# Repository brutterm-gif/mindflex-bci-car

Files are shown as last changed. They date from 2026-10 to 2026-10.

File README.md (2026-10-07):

# MindFlex BCI – EEG-controlled RC car

**English** | [Deutsch](README.de.md)

A brain-computer interface project: a modified MindFlex EEG headset sends its readings through
an Arduino – over USB or wirelessly via Bluetooth LE. A Python application analyses the signals
in real time, trains several machine-learning models on recorded sessions and turns their
predictions into driving commands for a self-designed, 3D-printed RC car with four motors.

Built as the practical part of a school research paper (*Seminarfacharbeit*) on
*“Brain-computer interfaces – how thoughts control machines”*.

<p align="center">
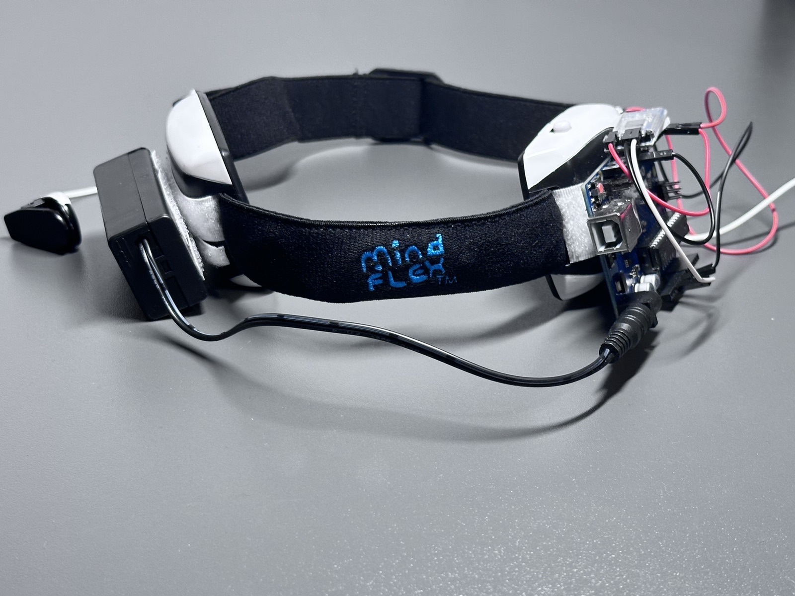
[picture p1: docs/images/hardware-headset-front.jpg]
The MindFlex headset from the front with Arduino and 9 V battery
  
</p>

<p align="center">
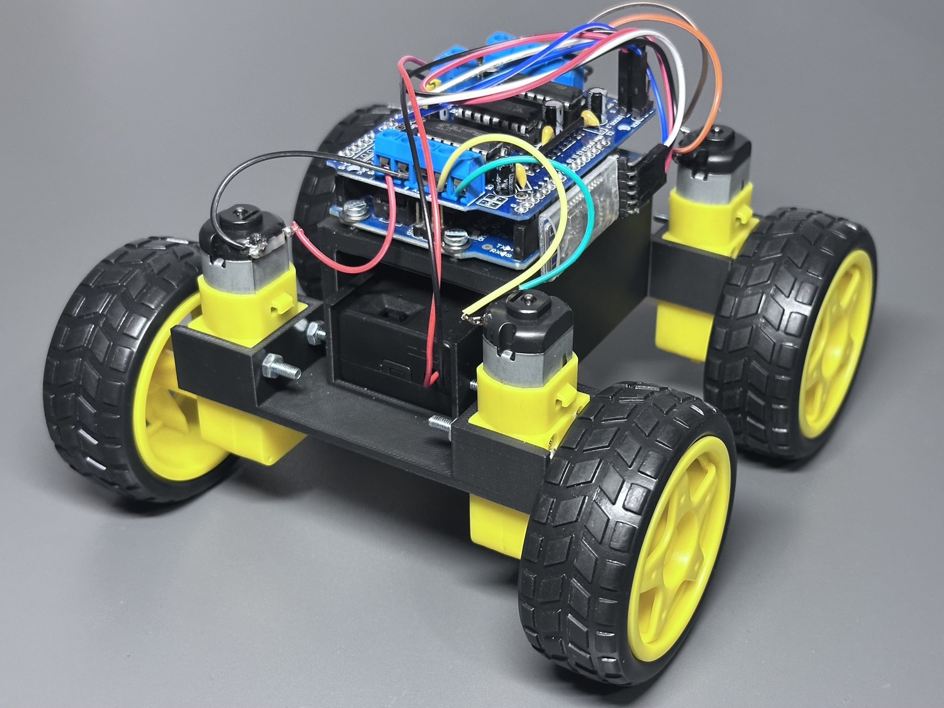
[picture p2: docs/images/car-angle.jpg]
The finished RC car with 3D-printed chassis, four motors and an Arduino with motor shield
  
</p>

**[⬇ Download version 3.4](https://github.com/brutterm-gif/mindflex-bci-car/releases/latest)** ·
[Parts list](docs/TEILELISTE.md) · [Wiring](docs/images/wiring.svg) ·
[Architecture](docs/ARCHITEKTUR.md)

> The application interface and the detailed documentation in `docs/` are in German.

## Screenshots

Live prediction with EEG history, eSense values, driving command and model accuracy:

| FORWARD | STOP |
|---|---|
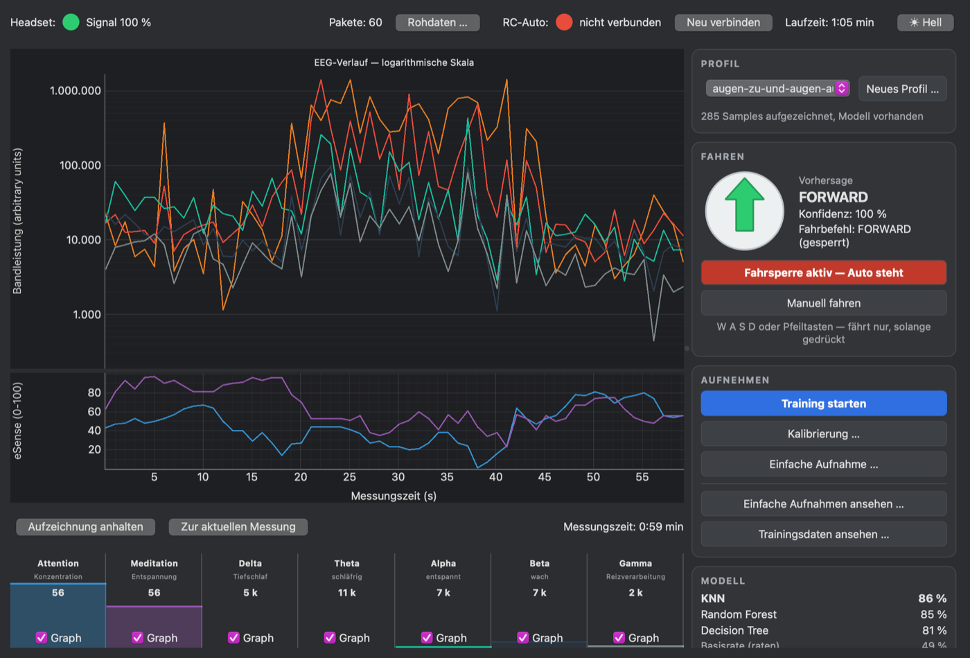
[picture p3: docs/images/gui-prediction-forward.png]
Prediction FORWARD
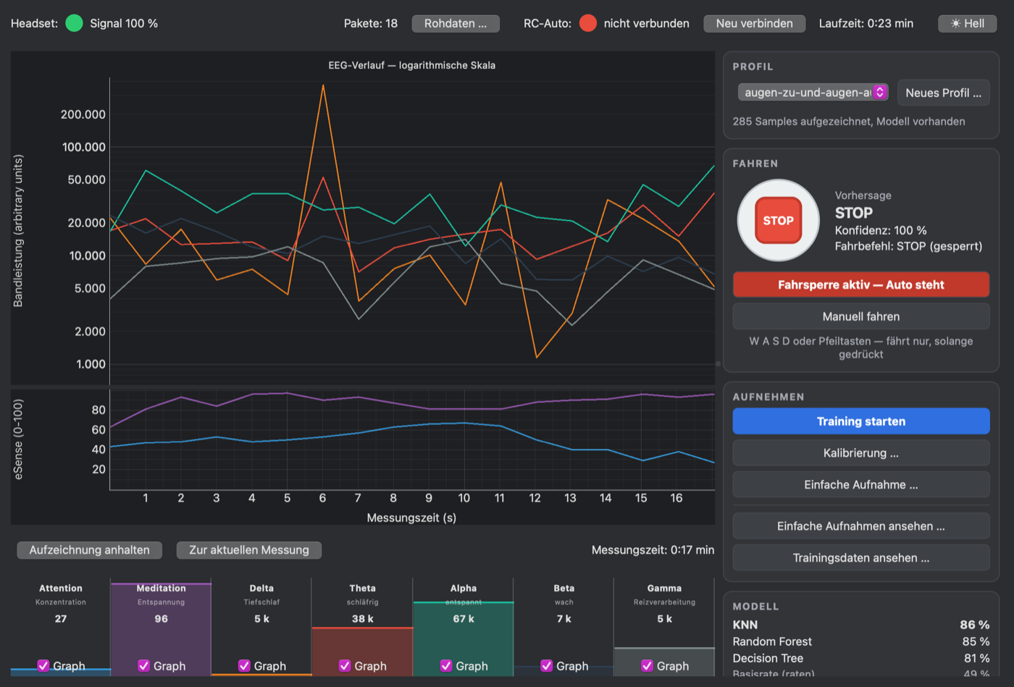
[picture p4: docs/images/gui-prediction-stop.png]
Prediction STOP
|  |  |

| Calibration | Confusion matrix |
|---|---|
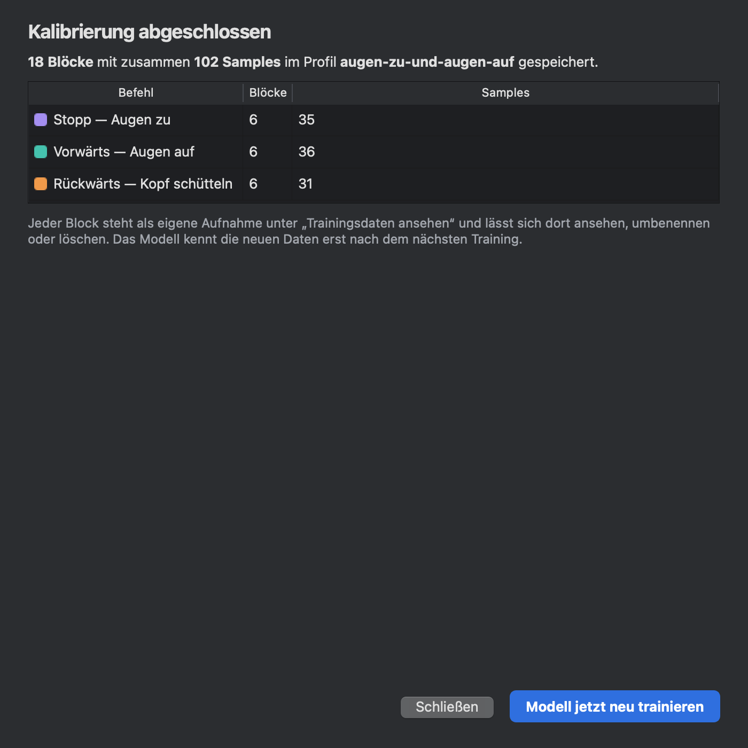
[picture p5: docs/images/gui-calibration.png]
Calibration finished
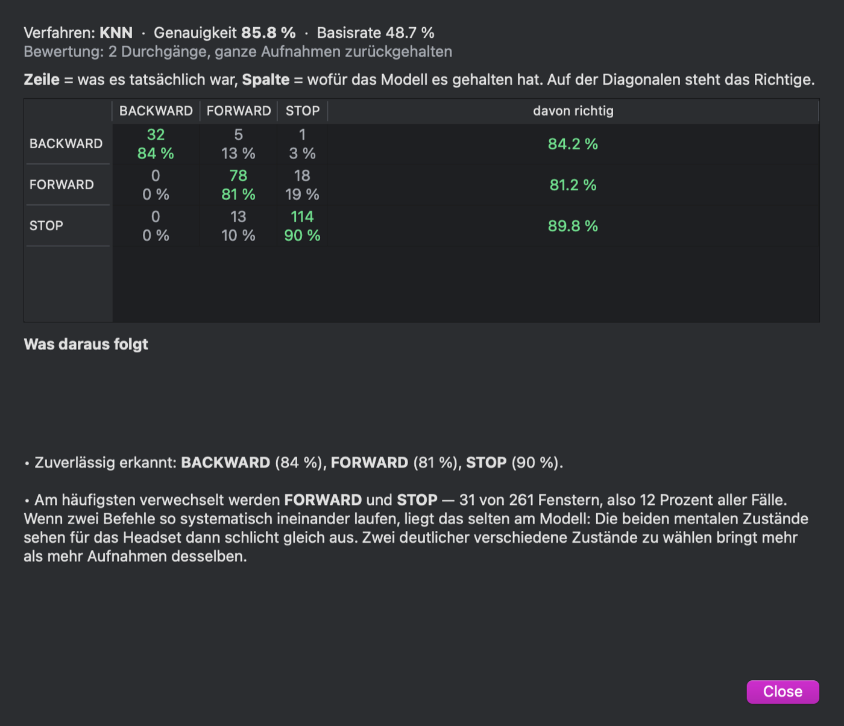
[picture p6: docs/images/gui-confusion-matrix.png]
Confusion matrix of the KNN model
|  |  |

<details>
<summary><b>More screenshots</b></summary>

| Prediction BACKWARD | Car connected, drive lock off |
|---|---|
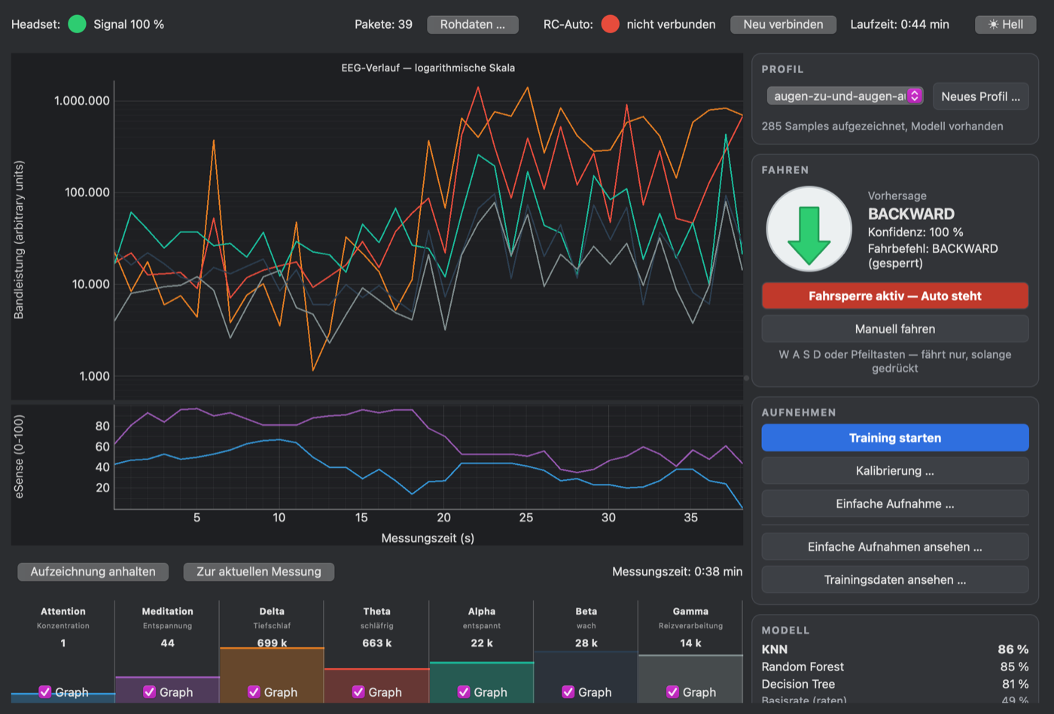
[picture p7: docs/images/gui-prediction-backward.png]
Prediction BACKWARD
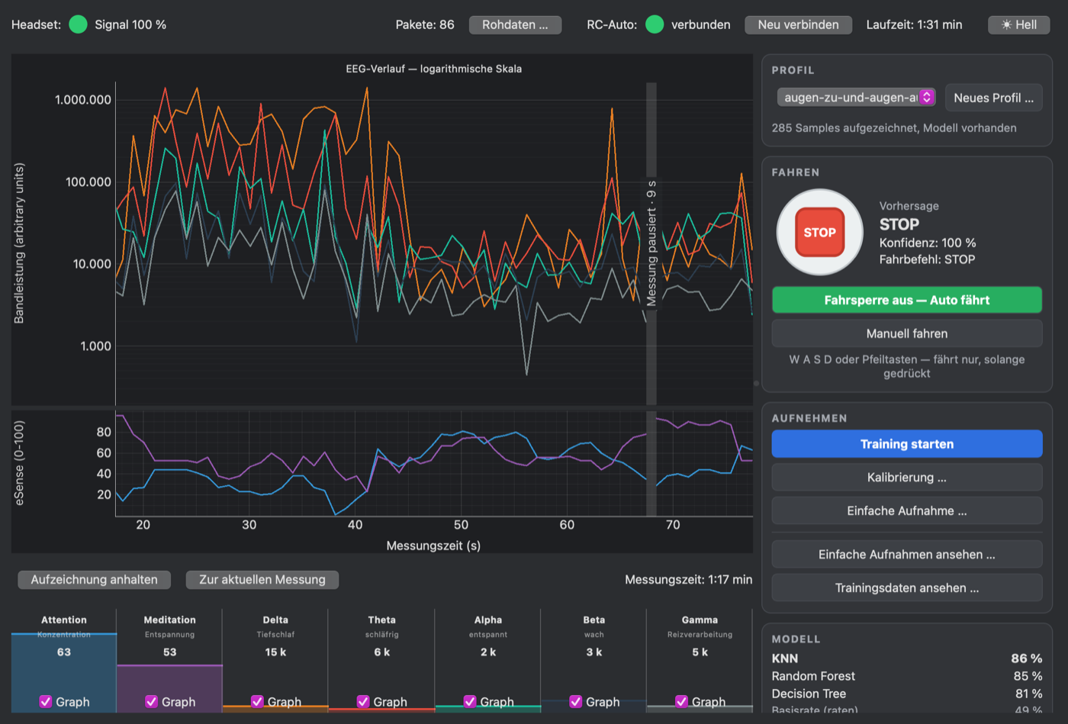
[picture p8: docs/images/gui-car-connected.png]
Car connected, drive lock off
|  |  |

| Manual driving (W A S D) | Headset without skin contact |
|---|---|
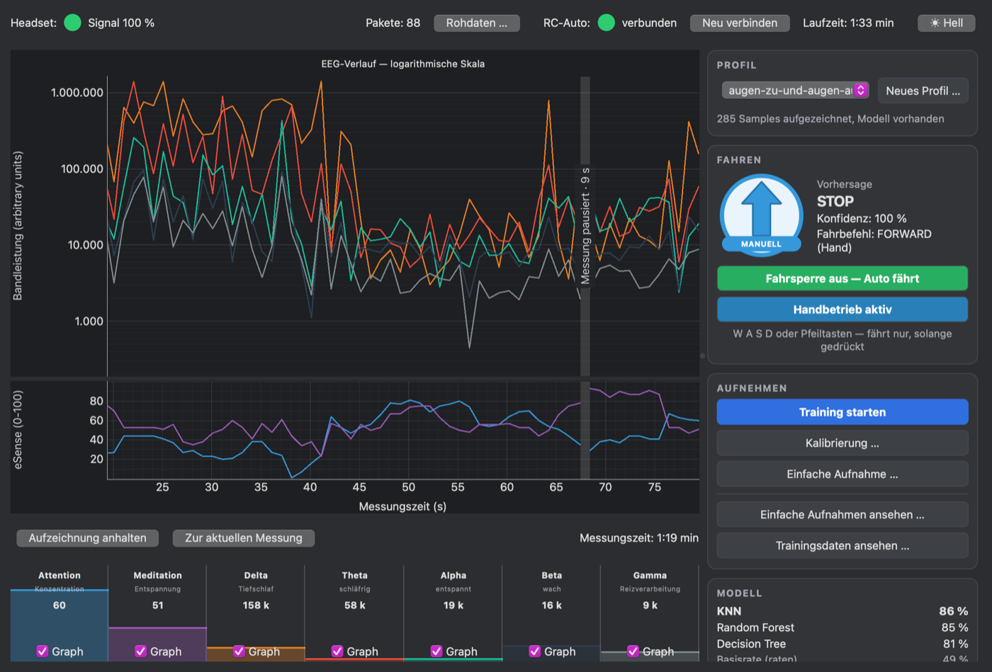
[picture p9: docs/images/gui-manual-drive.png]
Manual driving
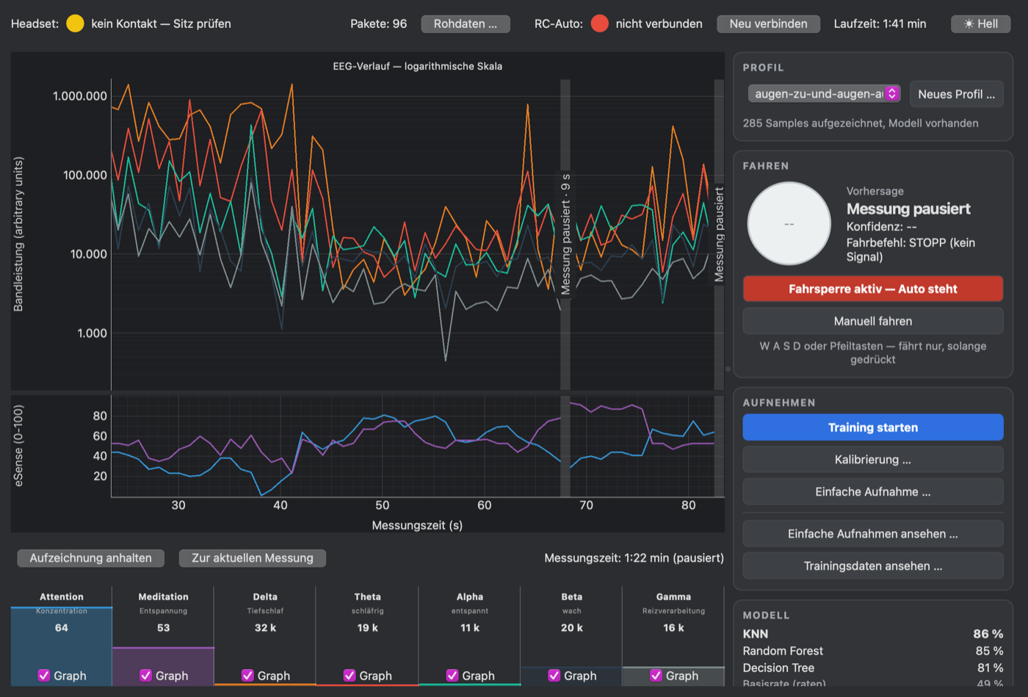
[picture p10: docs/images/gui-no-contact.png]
Headset without skin contact, recording paused
|  |  |

| Calibration running | Light mode |
|---|---|
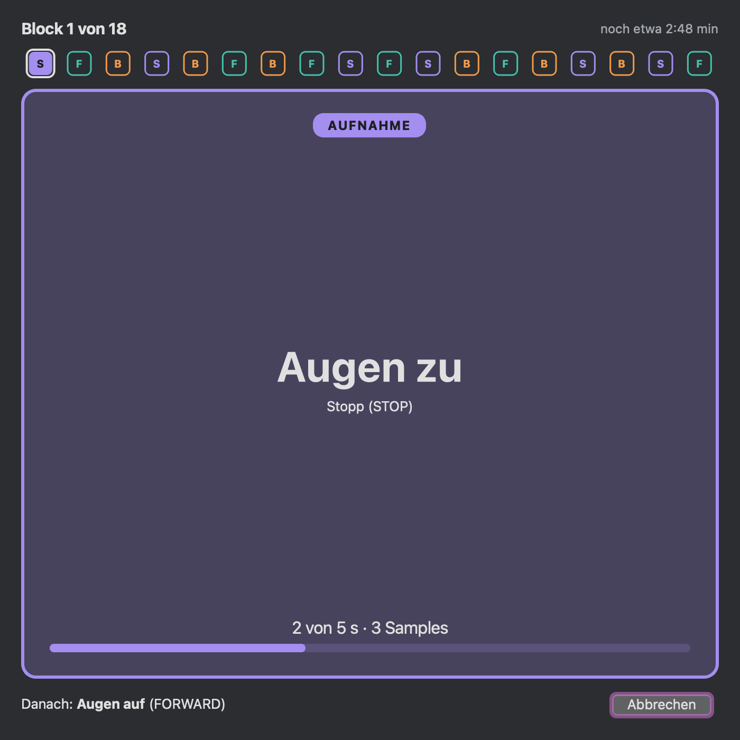
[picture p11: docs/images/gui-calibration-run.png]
Calibration: block 1 of 18, eyes closed
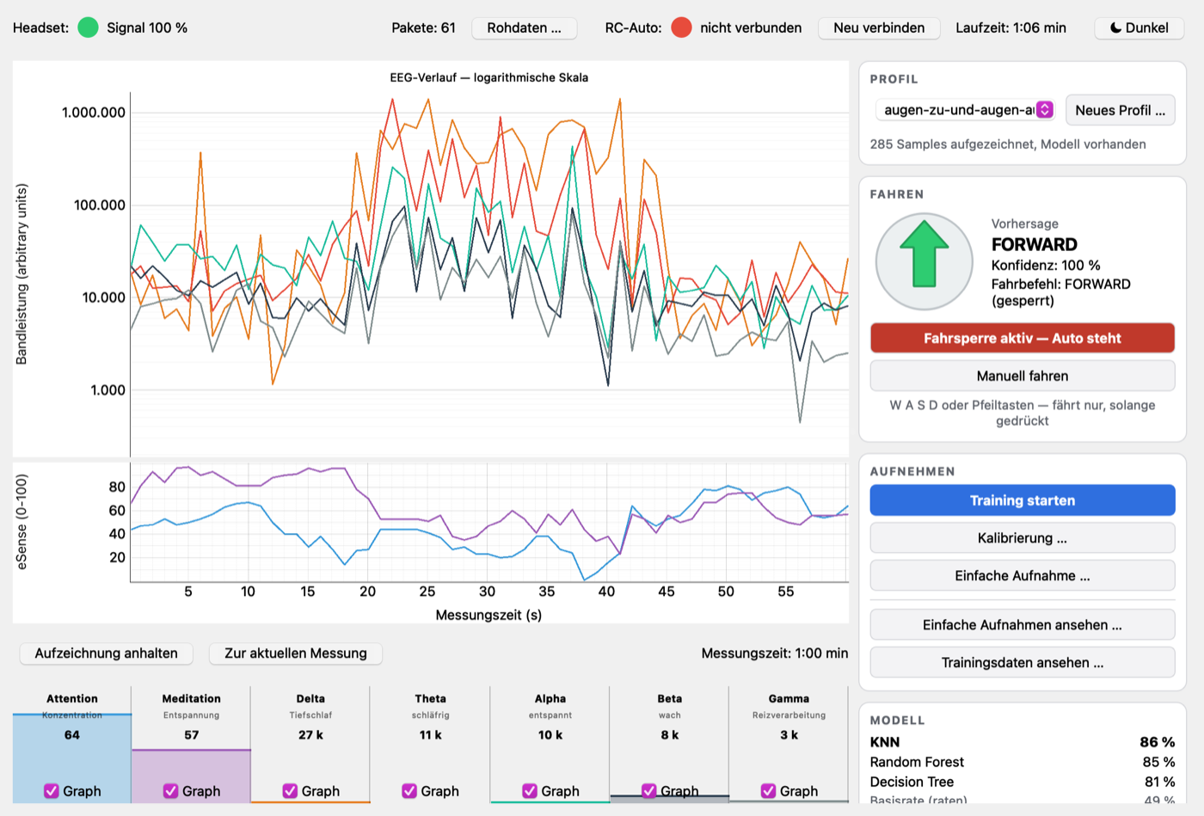
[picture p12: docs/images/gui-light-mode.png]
Light mode
|  |  |

| Training data with recommendations | Single recording as a graph |
|---|---|
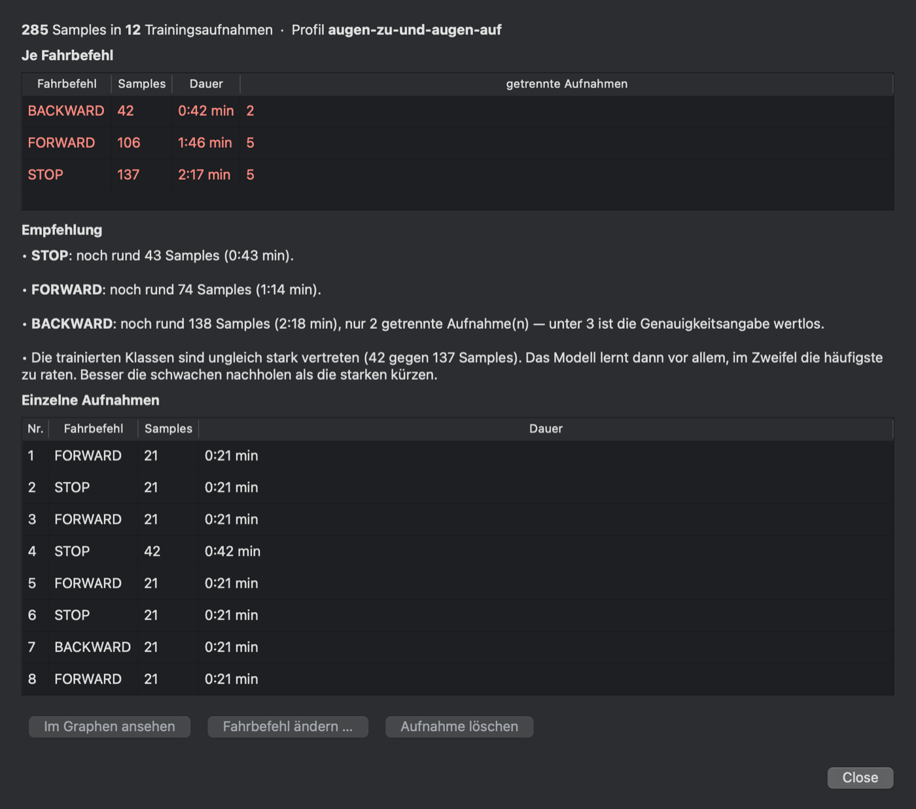
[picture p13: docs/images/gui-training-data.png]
Overview of the training data
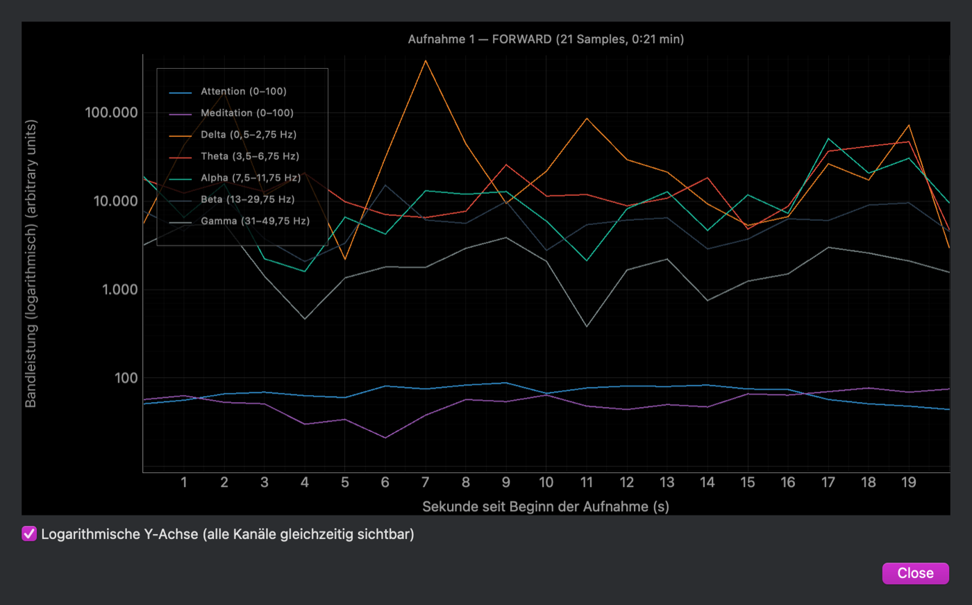
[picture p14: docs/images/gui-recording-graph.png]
Recording FORWARD as a graph
|  |  |

</details>

## Results

The headset measures with a single electrode on the forehead. That is enough to tell apart
states that show up clearly there – not “thinking left or right”. The car is therefore
controlled with three states you can produce on purpose:

| Command | What you do | Why it works |
|---|---|---|
| STOP | close your eyes | alpha waves rise sharply (Berger effect) |
| FORWARD | open your eyes | alpha drops again |
| BACKWARD | shake your head or clench your jaw | muscle signal picked up by the forehead electrode |

**Accuracy** (one profile, three commands, 12 recordings totalling 285 seconds, evaluated on
held-out whole recordings):

| Method | Accuracy |
|---|---|
| k-nearest neighbours | **85.8 %** |
| Random forest | 85 % |
| Decision tree | 81 % |
| Baseline (always guess the most frequent class) | 48.7 % |

STOP was recognised correctly 90 % of the time, BACKWARD 84 % and FORWARD 81 %. The most common
confusion is FORWARD vs. STOP – mostly right after opening the eyes, because alpha only drops
after 2–3 seconds.

These numbers are for one person and a small amount of data. BACKWARD has only two separate
recordings; the application itself warns that its figure is therefore still uncertain. Models
do not transfer between people; everyone needs their own profile.

## Project structure

```
MindFlex_BCI_Projekt/   Python application: data input (USB/BLE), feature extraction,
                        training and classification (KNN, random forest, decision tree),
                        PyQt5 GUI with calibration, profiles, drive lock and manual driving,
                        car control
  arduino/              sketches for the EEG Arduino and the RC car
BrainGrapher/           Processing sketch for live visualisation of the raw EEG values,
                        extended with a Bluetooth bridge (ble_bridge.py)
BrainGrapher_Python/    port of the BrainGrapher to Python (PyQt5/pyqtgraph)
hardware/               3D model of the chassis (STL)
docs/                   architecture, parts list, images
```

## Origin and own work

`BrainGrapher/` is based on the open-source
[Processing Brain Grapher](https://github.com/kitschpatrol/Processing-Brain-Grapher) by
Eric Mika (MIT licence, see [`BrainGrapher/LICENSE.txt`](BrainGrapher/LICENSE.txt)). It served
as the starting point for reliably receiving and visualising the headset's data. Bluetooth LE
support was added. `BrainGrapher_Python/` is a port of that sketch to Python.

The sketch `mindflex_eeg.ino` is based on the *BrainSerialTest* example of the
[Arduino Brain Library](https://github.com/kitschpatrol/Brain), also by Eric Mika.

`MindFlex_BCI_Projekt/` is original work: the data pipeline (validation, ring buffer, feature
extraction), the training and classification system with automatic selection of the best
model, the GUI with calibration and profiles, the Bluetooth link and the RC car control. The
sketch `rc_car_4wd.ino` and the chassis are original work as well.

## Hardware

All components: [parts list](docs/TEILELISTE.md). Wiring:

Wiring: headset with Arduino Uno, car with Duemilanove and L293D shield

1. **Headset and EEG Arduino (Uno):** The MindFlex contains NeuroSky's TGAM module. Two wires
   are soldered to its T pin and GND and lead to the Arduino. Using the
   [Arduino Brain Library](https://github.com/kitschpatrol/Brain), the Uno outputs one CSV line
   per second (SignalQuality, Attention, Meditation, Delta, Theta, LowAlpha, HighAlpha, LowBeta,
   HighBeta, LowGamma, HighGamma) – over USB or a BLE module. Arduino and radio sit directly on
   the headset, powered by a switched 9 V battery.

| Headset mit Arduino · Headset with Arduino | Vorderansicht · Front view |
|---|---|
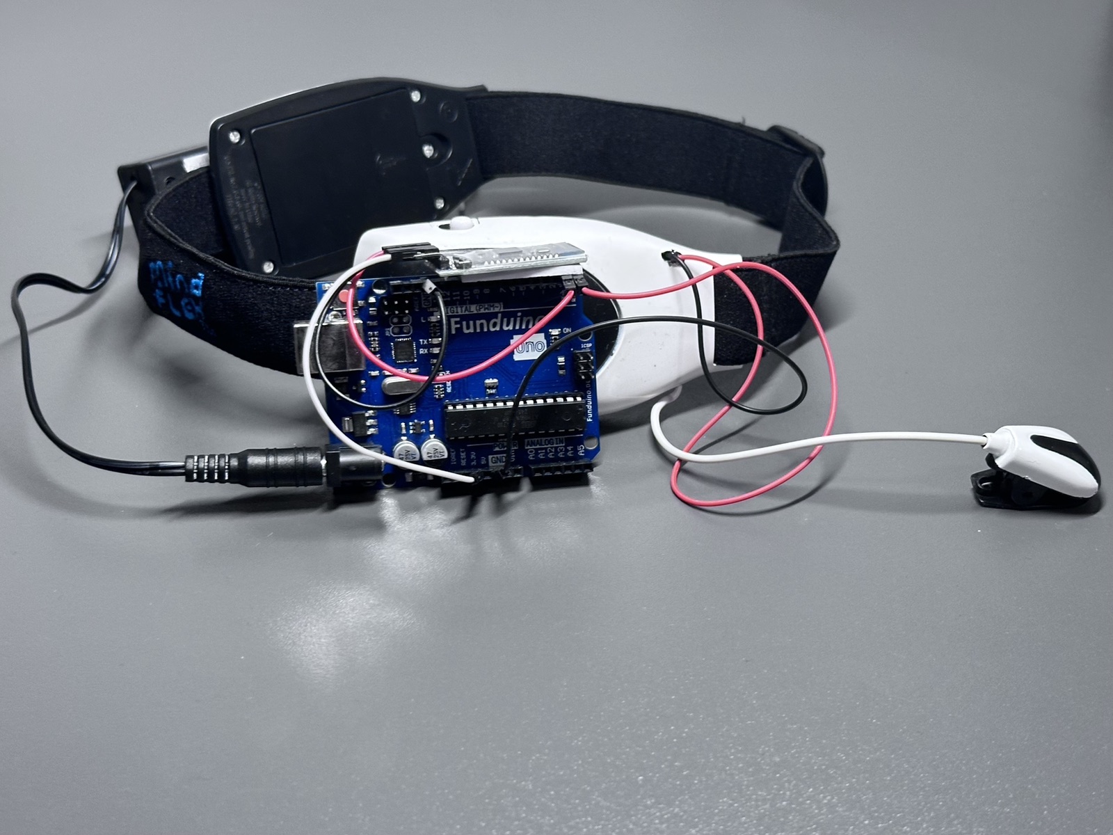
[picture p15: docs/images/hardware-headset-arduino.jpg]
MindFlex headset with Arduino Uno and BLE module attached
|  | MindFlex headset from the front |
| **Geöffnet: TGAM-Modul mit angelöteten Drähten · Opened: TGAM module with soldered wires** | **Rückseite: 9-V-Block und Ohrclip · Back: 9 V battery and ear clip** |
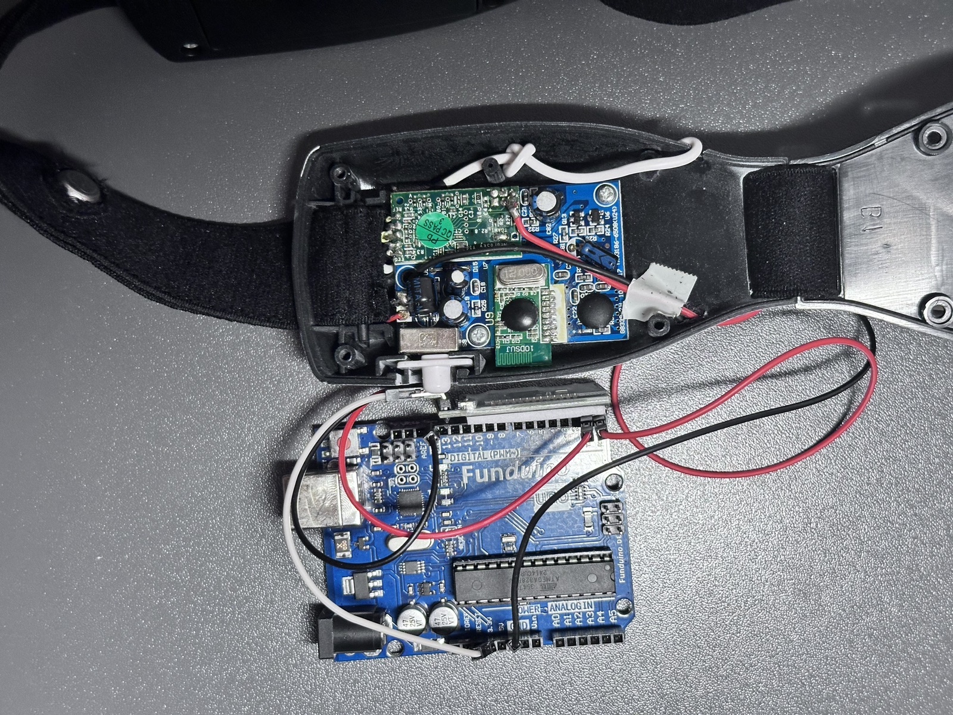
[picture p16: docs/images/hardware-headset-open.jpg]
Opened headset: green NeuroSky TGAM board with wires soldered on, leading to the Arduino
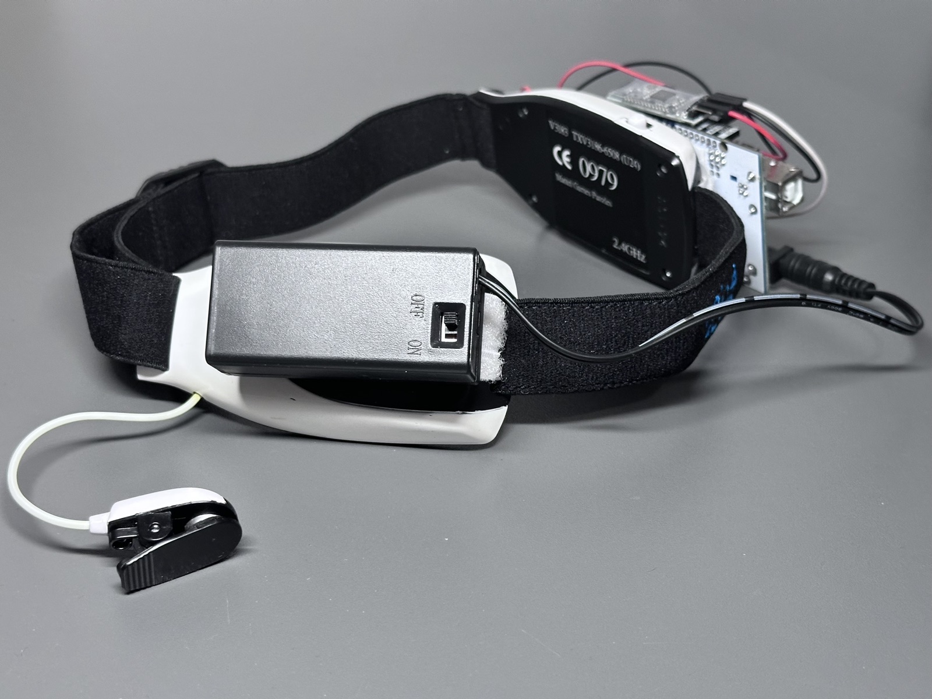
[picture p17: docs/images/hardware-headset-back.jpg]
Back of the headset with the 9 V battery box for the Arduino and the ear clip reference electrode
|  |  |

2. **RC car (Arduino Duemilanove):** receives single-character commands (`F`/`B`/`L`/`R`/`S`)
   over Bluetooth LE and drives four motors through an L293D motor shield. It steers like a
   tank: to turn, the two sides run in opposite directions. Power comes from a 9 V battery
   that sits inside the chassis below the Arduino.

| Seite mit 9-V-Block · Side with 9 V battery | Von oben · Top | Seite mit USB-Anschluss · Side with USB port |
|---|---|---|
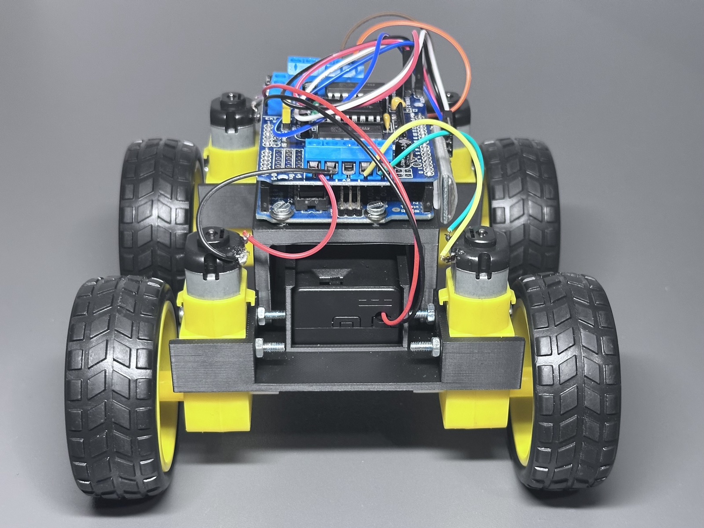
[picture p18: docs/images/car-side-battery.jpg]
RC car, side with the 9 V battery inside the chassis
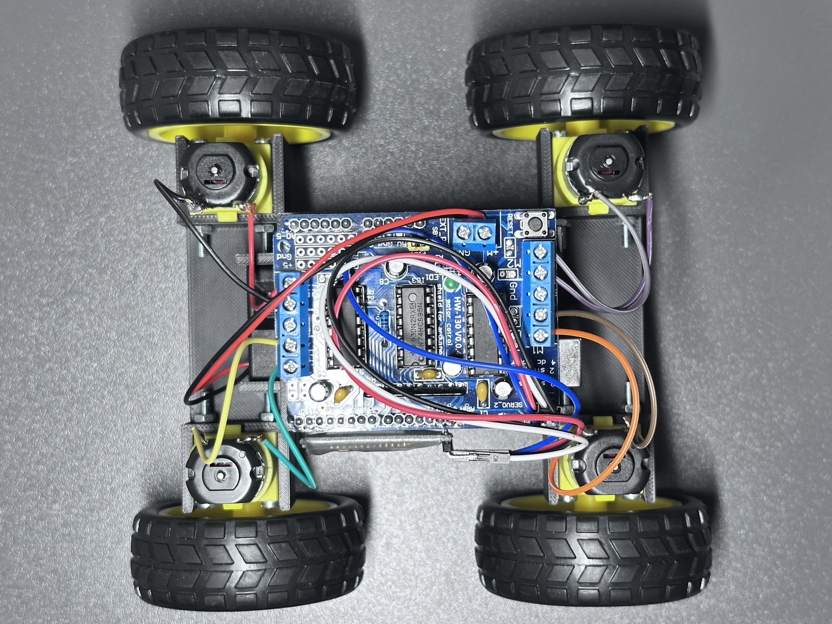
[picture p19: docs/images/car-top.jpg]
RC car from above: motor shield and wiring of the four motors
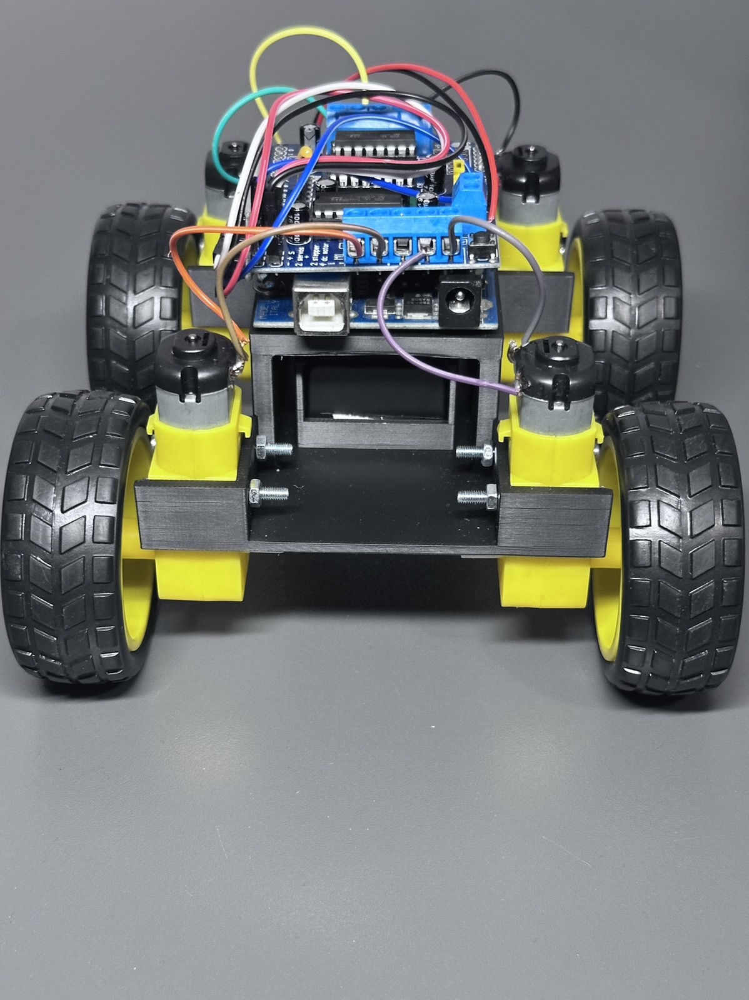
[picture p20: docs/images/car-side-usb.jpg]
RC car, side with the Arduino's USB port
|  |  |  |

| Chassis | Technische Zeichnung · Technical drawing |
|---|---|
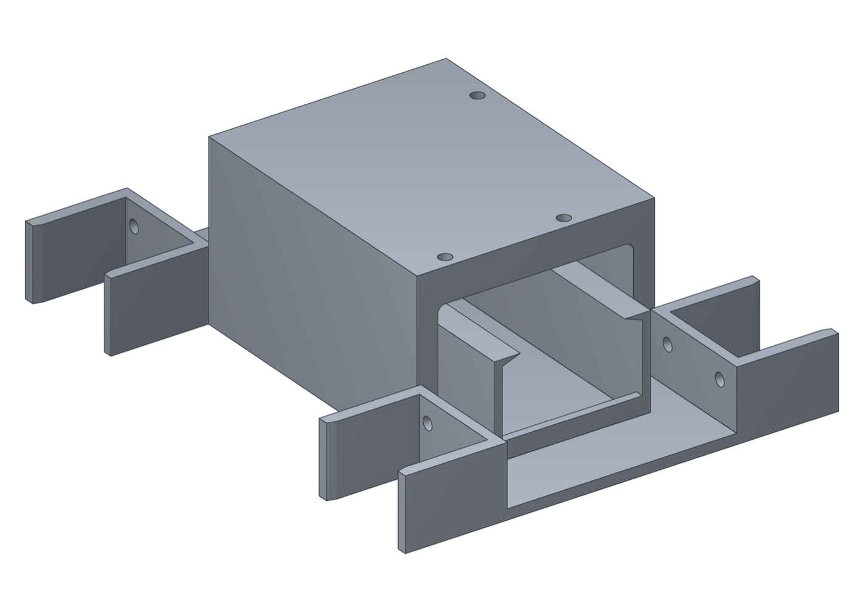
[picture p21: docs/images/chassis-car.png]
Chassis
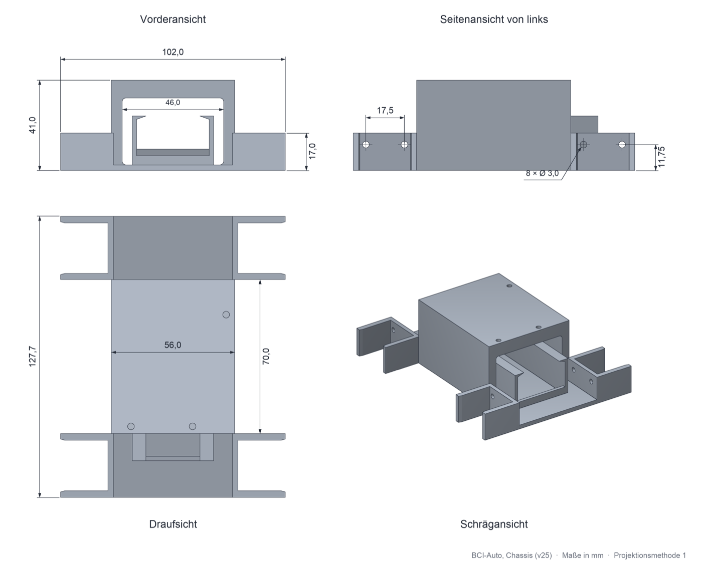
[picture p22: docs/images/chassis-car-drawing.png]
Dimensioned drawing of the chassis
|  |  |

The chassis is included as [`hardware/chassis_car.stl`](hardware/chassis_car.stl) and can be
printed directly.

## Quick start

**Requirements:** Python 3.12, the [Arduino IDE](https://www.arduino.cc/en/software) with the
[Arduino Brain Library](https://github.com/kitschpatrol/Brain) and the Adafruit Motor Shield
Library v1, optionally [Processing](https://processing.org/download) for `BrainGrapher/`.

1. Upload `MindFlex_BCI_Projekt/arduino/mindflex_eeg/mindflex_eeg.ino` to the EEG Arduino and
   `MindFlex_BCI_Projekt/arduino/rc_car_4wd/rc_car_4wd.ino` to the car's Arduino.
2. Start the Python application:

```bash
cd MindFlex_BCI_Projekt
pip install -r requirements.txt
python main.py
```

On a Mac you can also double-click `start.command`, on Windows `start.bat`. Setting up
Bluetooth, creating a profile and calibrating are described (in German) in
[`MindFlex_BCI_Projekt/README.md`](MindFlex_BCI_Projekt/README.md).

For signal visualisation only, open `BrainGrapher/BrainGrapher.pde` in the Processing IDE
(requires the ControlP5 library, available via *Sketch → Import Library → Add Library*).

## Data flow

MindFlex BCI pipeline

## Privacy

Training profiles and EEG recordings of test participants are not part of this repository.
Everyone creates and calibrates their own profile in the application; the data stays local in
the `profile/` folder.

## Licence

- `MindFlex_BCI_Projekt/`, `hardware/`, `docs/`: MIT, see [`LICENSE`](LICENSE)
- `BrainGrapher/`, `BrainGrapher_Python/`: MIT, Copyright (c) 2010-2025 Eric Mika, see
  [`BrainGrapher/LICENSE.txt`](BrainGrapher/LICENSE.txt); extensions MIT, see [`LICENSE`](LICENSE)

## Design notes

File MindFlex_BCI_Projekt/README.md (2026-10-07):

# MindFlex BCI – Anleitung

Die Python-Anwendung zum Projekt. Überblick und Hardware: [Haupt-README](../README.md),
technische Details: [`docs/ARCHITEKTUR.md`](../docs/ARCHITEKTUR.md).

## 1. Installieren

Benötigt wird **Python 3.12** ([python.org](https://www.python.org/downloads/)). Unter Windows
bei der Installation den Haken bei **„Add python.exe to PATH“** setzen.

**Mac:** Doppelklick auf `start.command`. Beim ersten Start richtet das Skript eine eigene
Python-Umgebung (`.venv`) ein und installiert die Pakete – das dauert ein paar Minuten. Meldet
macOS „nicht verifizierter Entwickler“: Rechtsklick auf `start.command` → Öffnen.

**Windows:** In diesem Ordner ein Terminal öffnen und einmalig

```
pip install -r requirements.txt
```

ausführen, danach Doppelklick auf `start.bat`.

**Von Hand (alle Systeme):**

```bash
pip install -r requirements.txt
python main.py
```

## 2. Arduinos vorbereiten

Die Sketches liegen in [`arduino/`](arduino):

| Sketch | Board | Bibliothek |
|---|---|---|
| `mindflex_eeg/` | Arduino Uno am Headset | [Arduino Brain Library](https://github.com/kitschpatrol/Brain) |
| `rc_car_4wd/` | Arduino Duemilanove im Auto | Adafruit Motor Shield Library **v1** (`AFMotor`) |
| `rc_car_test/` | Auto-Arduino, ohne Motoren | – |

Vor dem Hochladen auf den Uno das Headset ausschalten – sein Datenstrom an Pin 0 stört
sonst den Upload. Im Auto-Sketch prüft man mit `T` im Seriellen Monitor, ob alle Räder
vorwärts drehen, und stellt falsch laufende Motoren in `INVERT[]` um.

## 3. Bluetooth einrichten

Das Auto wird standardmäßig per Bluetooth angesteuert, das Headset standardmäßig per
USB-Kabel. Die Funkmodule sind BLE-Module (CC2541) und tauchen **nicht** in den
Bluetooth-Einstellungen auf.

1. Nur das Auto einschalten, dann

   ```bash
   python ble_scan.py
   ```

   Das Programm listet alle Module mit dem Dienst `FFE0` auf.
2. Adresse übernehmen – entweder dauerhaft in `config.py` (`MINDFLEX_CAR_BLE_ADDRESS`) oder
   beim Start:

   ```bash
   MINDFLEX_CAR_BLE_ADDRESS=<Adresse> python main.py
   ```

3. Zum Testen ohne EEG: `python ble_test.py` schickt jeden Befehl einmal,
   `python ble_remote.py` steuert das Auto mit W A S D (nur Mac und Linux).

Unter macOS ist die Adresse eine UUID, die auf jedem Mac anders ist – auf einem neuen Rechner
also neu suchen.

**Headset per Funk** statt Kabel (Uno mit eigenem BLE-Modul, nur das Headset eingeschaltet
lassen und ebenfalls mit `ble_scan.py` suchen):

```bash
MINDFLEX_EEG_TRANSPORT=ble MINDFLEX_EEG_BLE_ADDRESS=<Adresse> python main.py
```

## 4. Erste Schritte in der Oberfläche

1. **Profil anlegen** (oben rechts, „Neues Profil …“). Jede Person braucht ein eigenes Profil,
   denn EEG-Muster unterscheiden sich stark. Gespeichert wird in `profile/<name>/`.
2. **Headset aufsetzen** und warten, bis oben „Signal 100 %“ steht. Gelb heißt: Sitz prüfen.
3. **Kalibrierung …** starten. Das Programm führt durch 18 kurze Blöcke und sagt auf dem Mac
   jede Anweisung an (Voreinstellung: Augen zu = STOP, Augen auf = FORWARD, Kopf schütteln =
   BACKWARD; die Anweisungen lassen sich ändern). Danach „Modell jetzt neu trainieren“.
4. **Genauigkeit prüfen:** Unten rechts stehen die drei Verfahren und die Basisrate. Liegt das
   beste Verfahren nicht klar über der Basisrate, mehr Daten aufnehmen. Über
   „Trainingsdaten ansehen …“ gibt es Empfehlungen, welche Befehle noch Daten brauchen.
5. **Fahren:** Fahrsperre lösen. Mit „Manuell fahren“ lässt sich das Auto jederzeit per
   Tastatur übernehmen – es fährt nur, solange eine Taste gedrückt ist.

## 5. Weitere Startoptionen

```bash
python main.py --mode train     # Training in der Konsole statt in der Oberfläche
python main.py --mode retrain   # Modell des Profils einmal neu trainieren und beenden
```

| Umgebungsvariable | Wirkung |
|---|---|
| `MINDFLEX_PROFIL=<name>` | mit diesem Profil starten |
| `MINDFLEX_EEG_PORT=<port>` | Port des Uno fest vorgeben (z. B. `COM5` oder `/dev/cu.usbmodem…`) |
| `MINDFLEX_CAR_TRANSPORT=serial` | Auto per USB-Kabel statt Bluetooth, Port mit `MINDFLEX_CAR_PORT` |
| `MINDFLEX_ACTIVE_LABELS=STOP,FORWARD` | nur diese Befehle trainieren und vorhersagen |

Unter Windows werden Umgebungsvariablen vorher mit `set NAME=Wert` gesetzt. Das Programm
schreibt ein Protokoll nach `mindflex_bci.log`.

## 6. Dateien

| Datei | Inhalt |
|---|---|
| `main.py` und die übrigen `.py`-Dateien | das Programm |
| `config.py` | alle Einstellungen an einer Stelle |
| `profile/` | entsteht beim ersten Start; je Person Trainingsdaten, Modell und Kalibrierung. **Wird nicht zu GitHub hochgeladen.** |
| `arduino/` | die drei Sketches |
| `requirements.txt` | benötigte Python-Pakete |

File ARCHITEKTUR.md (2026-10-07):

# BCI MindFlex Car - Gesamte Vorgehensweise

Vollständige Dokumentation des BCI-Projekts: Von der Hardware-Integration über Datenerfassung bis zur KI-gesteuerten Fahrzeugkontrolle. Ein Python-basiertes System, das EEG-Signale eines MindFlex-Headsets in Echtzeit klassifiziert und daraus Fahrbefehle für ein RC-Auto ableitet.

---

## 1. Projektübersicht & Ziele

### Was ist das Projekt?

Das BCI MindFlex Car Projekt ist ein **Gedankensteuersystem für ein Fahrzeug**:
- Du trägst ein **EEG-Headset** (NeuroSky MindFlex)
- Du denkst an eine Fahrtrichtung (FORWARD, STOP, LEFT, RIGHT, BACKWARD)
- Ein **Machine-Learning-Modell** übersetzt deine Gehirnwellen in Fahrbefehle
- Ein **RC-Auto mit vier Motoren** führt diese Befehle aus

### Systemarchitektur (Datenfluss)

```
MindFlex Headset (EEG-Messungen)
        |
        v
Arduino Uno (ThinkGear-Protokoll, serieller Port)
        |
        v
Python-Anwendung (Klassifikation, GUI)
        |
        +----> Signalvalidierung & Feature-Extraktion
        |
        +----> ML-Klassifikation (Decision Tree / Random Forest / KNN)
        |
        v
BLE-Funkmodul
        |
        v
Arduino Duemilanove (Motorsteuerung)
        |
        v
L293D Shield + 4 Getriebemotoren (RC-Auto)
```

### Warum diese Architektur?

- **Zwei separate Arduinos:** Der Uno liest EEG-Daten, der Duemilanove steuert die Motoren. Das erlaubt unabhängige Fehlerbehandlung — fällt das Auto aus, läuft die Klassifikation trotzdem weiter.
- **BLE statt Klassisches Bluetooth:** Stabil auf macOS 15+, während klassisches SPP (Serial Port Profile) dort anfällig für Verbindungsabbrüche ist.
- **Python statt Arduino-Code für die KI:** Auf dem Mac kann man die ML-Modelle trainieren und debuggen, bevor man sie einsetzt.

---

## 2. Hardware-Setup

### Komponenten

**EEG-Erfassung:**
- NeuroSky MindFlex Headset (misst mit einer Elektrode auf Fp1, Referenz am Ohr)
- Arduino Uno (liest ThinkGear-Protokoll über RX-Pin)
- USB-Kabel oder BLE-Modul (CC2541 / HM-10) für drahtlose Verbindung

**Fahrzeugsteuerung:**
- Arduino Duemilanove (ATMEGA328P-PU)
- L293D Motor Shield (HW-130) für 4 DC-Motoren
- 4 Getriebemotoren (90°-Zahnräder, beliebige Drehzahl)
- 4 AA-Batterien oder LiPo (nicht 9V Block — zu schwach!)
- Bluetooth Low Energy Modul (CC2541/HM-10/AT-09) am Duemilanove

### Verkabelung: EEG-Arduino (Uno)

```
MindFlex Headset  -> RX-Pin (Pin 0)
ThinkGear Chip (aus Headset) -> RX-Pin
      |
CSV-Datenzeile (fertig aufbereitet) -> TX-Pin (Pin 1)
```

**Optional: BLE-Modul statt USB**

Wenn du das Headset funken lassen willst (2. BLE-Modul):

```
Modul VCC    -> 5V
Modul GND    -> GND
Modul RXD    -> Pin 1 (TX) über Spannungsteiler 1 kΩ / 2 kΩ   ⚠️ Zwingend!
```

Der Spannungsteiler ist **notwendig**, weil Pin 1 den Datenstrom direkt empfängt.

### Verkabelung: Auto-Arduino (Duemilanove)

```
HC-05 / HM-10 Modul
    VCC -> 5V oder 3,3V (beide getestet, Verbindung steht)
    GND -> GND
    TXD -> Pin 10 (über SoftwareSerial)
    RXD -> offen (Arduino sendet nichts zurück)

L293D Shield
    M1 -> vorne rechts
    M2 -> vorne links
    M3 -> hinten rechts
    M4 -> hinten links

Alle vier INVERT-Schalter im Sketch auf true (Motoren sind einheitlich gepolt)
```

**Versorgung:** Der Duemilanove hat auch einen 3,3-V-Pin (vom FTDI-Chip FT232RL, max. ca. 50 mA). Das BLE-Modul (ca. 10 mA) läuft daran ebenfalls, getestet am 2026-09-29.

**Wichtig:** Pin 11 darf NICHT verwendet werden (PWM für Motor 1), deshalb Pin 10 für BLE.

---

## 3. Komponenten-Auswahl & Begründung

Dieses Kapitel erklärt, **warum** wir diese Hardware-Komponenten gewählt haben und welche **Vorteile** sie bringen — im Vergleich zu Alternativen.

### 3.1 EEG-Headset: NeuroSky MindFlex

#### Warum MindFlex?

**Das MindFlex ist ein Spielzeug-Headset** — das war Absicht! Es war die verfügbare und kostengünstige Lösung für Schüler:innen im Seminarfach.

| Kriterium | MindFlex | Professionell (z.B. Muse, Emotiv) | Forschung (z.B. BioSemi) |
|---|---|---|---|
| **Kosten** | €80–120 | €300–500 | €10.000+ |
| **Kanäle** | 1 (Fp1) | 4–32 | 64–256 |
| **Auflösung** | ??? (proprietär) | 14–16 Bit | 24 Bit |
| **Sampling-Rate** | ~ 512 Hz (internal) | 256–500 Hz | 2000 Hz |
| **ThinkGear API** | Ja (CSV) | Nein, eigene Protokolle | Nein |
| **Praxistauglichkeit** | Eher spielerisch | Professionell | Forschung |

#### Vorteile des MindFlex

1. **Einfaches Protokoll (ThinkGear)**
   - Das Headset sendet **aufbereitete EEG-Bänder** (Delta, Theta, Alpha, Beta, Gamma), nicht Rohdaten
   - Intern läuft ein ThinkGear-Chip (Infineon), der das Rohsignal schon filtert und analysiert
   - Ausgang ist einfaches CSV: `SignalQuality,Attention,Meditation,Delta,...`
   - **Vorteil:** Keine komplexe Signalverarbeitung nötig, einfach auswerten

2. **Komfort**
   - Trockenelektrode (kein Elektrogel nötig, schnell anzulegen)
   - Leicht (ca. 50 Gramm)
   - Ohrclip als Referenzelektrode (eher unauffällig)

3. **Kostengünstig**
   - Für ein Schulprojekt ideal
   - Wenn es kaputt geht, nicht tragisch

4. **Brain Library für Arduino**
   - Arduino-Community hat bereits eine fertige `Brain`-Bibliothek geschrieben
   - Kommunikation mit dem Headset funktioniert Out-of-the-Box

#### Nachteile & Einschränkungen

1. **Nur eine Elektrode (Fp1)**
   - Sitzt auf der Stirn
   - Misst eher Frontal-Aktivität (Aufmerksamkeit, Meditationszustand)
   - **Motorischer Kortex (C3/C4, wo Bewegungen geplant werden) ist nicht erreichbar**
   - → LEFT/RIGHT-Bewegungen sind möglicherweise nicht im Signal sichtbar

2. **Propriätärer ThinkGear-Chip**
   - Keine Rohdaten zugänglich
   - Wir wissen nicht genau, wie die Algorithmen funktionieren
   - Keine Kontrolle über Filterung/Verarbeitung

3. **Trockenelektrode ist anfällig**
   - Haare unter der Elektrode = schlechter Kontakt
   - Schweiß/Bewegung erzeugen Artefakte
   - Signal ist nicht stabil wie bei professionellen Headsets

4. **Signalqualität nicht dokumentiert**
   - Das Headset meldet `SignalQuality`, aber die Skala ist nicht klar (0–200? 0–100?)
   - Threshold `signal_quality == 200` für "kein Signal" wurde empirisch gefunden

#### Alternativen (und warum nicht?)

**Emotiv Epoc (4 Kanäle, ~€300)**
- ✅ Besser als MindFlex (4 Kanäle statt 1)
- ❌ Immer noch Spielzeug-Level
- ❌ Kostet das 3–4-fache
- ❌ Benötigt eigene Software-Stack (unterschiedlich von MindFlex)

**Muse Headband (4 Kanäle, ~€300)**
- ✅ Stabil auf macOS
- ✅ Gute BLE-Integration
- ❌ Kosten
- ❌ Weniger Gemeinschafts-Support als MindFlex

**OpenBCI (8–16 Kanäle, ~€500–800)**
- ✅ Open-Source Hardware
- ✅ Rohdaten verfügbar
- ✅ Gute Dokumentation
- ❌ Sehr teuer
- ❌ Komplexere Setup

**Fazit:** Für ein Schulprojekt mit kleinerem Budget war MindFlex die richtige Wahl.

---

### 3.2 Microcontroller: Arduino Uno & Duemilanove

#### Warum zwei Arduinos?

```
❌ Eine Lösung: Ein Arduino (Uno) für alles
   → Problem: Uno kann Python nicht ausführen
   → Python läuft auf dem Mac, Arduino-Sketch auf der Hardware
   → Wenn wir alles auf dem Uno machen, müssen wir ML-Klassifikation in C++ schreiben
   → Scikit-learn gibt es nicht für Arduino

✅ Zwei Lösungen: Uno (EEG) + Duemilanove (Auto)
   → Uno: Spezialisiert auf einfache Daten-Erfassung (EEG-Protokoll)
   → Duemilanove: Spezialisiert auf Motor-Steuerung
   → Python auf dem Mac: ML, Training, GUI
   → Entkopplung ermöglicht unabhängiges Debuggen
```

#### Arduino Uno: EEG-Erfassung

**Warum Uno?**

| Kriterium | Uno | Nano | Mega |
|---|---|---|---|
| **Größe** | Standard | Klein | Groß |
| **Speicher (Flash)** | 32 KB | 32 KB | 256 KB |
| **Speicher (RAM)** | 2 KB | 2 KB | 8 KB |
| **UART-Ports** | 1 | 1 | 4 |
| **Pin-Count** | 14 (6 PWM) | 14 (6 PWM) | 54 (15 PWM) |
| **Kosten** | €20 | €15 | €35 |
| **Häufigkeit** | Standard | Mobil/embedded | Komplex |

**Vorteile für EEG-Aufgabe:**
1. **Ausreichende Specs:** EEG-Daten sind einfache CSV-Zeilen, brauchen wenig RAM
2. **Brain Library Support:** Community hat fertige Brain-Bibliothek
3. **Standard-Hardware:** Leicht zu debuggen, überall verfügbar
4. **USB-Anschluss:** Direkte Verbindung zum Mac

**Nachteile:**
- Nur 2 KB RAM (nicht viel Platz für Buffer)
- Nur 1 UART (Hardware), aber das reicht für serielle EEG-Daten

**Warum nicht Nano?**
- Spart nur €5, das ist es nicht wert
- Uno ist handlicher auf einem Breadboard

**Warum nicht Mega?**
- Overkill für nur Datenerfassung
- Kostet mehr ohne echten Gewinn

---

#### Arduino Duemilanove: Motor-Steuerung

**Warum Duemilanove (ATMEGA328P)?**

Moment — **das ist eigentlich ungewöhnlich.** Der Duemilanove ist eine ältere Arduino-Variante (2009). Im Projekt wird er verwendet, weil:

1. **Verfügbar:** Er war im Bestand vorhanden
2. **Bootloader-kompatibel:** Funktioniert mit dem AFMotor-Shield (HW-130)
3. **Hardware-UART:** Gut für Motor-Kommunikation

Moderne Alternativen wären:

| Variante | Vorteil | Nachteil |
|---|---|---|
| **Arduino Uno** | Standardversion, überall | Nur 1 Hardware-UART |
| **Arduino Mega** | 4 Hardware-UARTs | Oversized für diese Aufgabe |
| **Arduino Nano** | Klein | Zu eng für Shield |
| **Arduino Pro Mini** | Stromsparen | Keine serielle Upload-Unterstützung |

**Duemilanove als Motor-Steuerung:**

✅ **Vorteile:**
- Genug Pins für L293D-Shield (11, 3, 5, 6, 4, 7, 8, 12 belegt)
- Kompatibel mit AFMotor-Library
- Stabil & bewährt

⚠️ **Nachteile:**
- Nur 1 Hardware-UART (aber genug für SoftwareSerial)
- Ältere Technologie (aber nicht schlecht)

---

### 3.3 Motor-Shield: L293D (HW-130) vs. Alternativen

#### Warum L293D Shield?

Das **L293D ist ein H-Brücken-IC**, das bis zu 4 DC-Motoren steuern kann. Es wird über ein Schieberegister (74HC595) angesteuert.

#### Vergleich Motor-Driver-Optionen

| Shield | Kanäle | Strom/Kanal | Kosten | Komplexität | Stabilität |
|---|---|---|---|---|---|
| **L293D (HW-130)** | 4 | 500 mA | €8–10 | Mittel (Schieberegister) | Gut |
| **L298N-Module** | 2 | 2 A | €5–7 | Einfach (direkt pins) | Gut |
| **DRV8833** | 2 | 1.5 A | €4–6 | Einfach | Sehr gut |
| **TB6612FNG** | 2 | 1.2 A | €3–5 | Einfach | Sehr gut |
| **L298N-Dual** | 4 | 2 A | €12–15 | Mittel | Gut |

#### Vorteile des L293D (HW-130)

1. **Vier unabhängige Kanäle**
   - Perfekt für 4-Rad-Fahrzeug mit separater Motorsteuerung pro Rad
   - Panzer-Lenkung möglich (jede Seite einzeln ansteuern)

2. **Arduino-fertig**
   - AFMotor-Bibliothek existiert bereits
   - Keine Custom-Verkabelung nötig
   - Plug-and-Play (auf Arduino aufgesteckt)

3. **Schieberegister-Steuerung**
   - Verwendet nur 4 Pins für Datenkommunikation (SPI-ähnlich)
   - Spart viele GPIO-Pins (Duemilanove hat nicht so viele)

4. **Stromverteilung**
   - Externe Stromversorgung möglich (Batterien direkt ans Shield)
   - Entlastet die Arduino-Stromversorgung

#### Nachteile

1. **Schieberegister ist komplex**
   - Weniger intuitiv als direkte Pin-Ansteuerung
   - Bei Fehler schwerer zu debuggen

2. **500 mA pro Kanal können grenzwertig sein**
   - Mit 4 Motoren gleichzeitig × 500 mA = 2 A Gesamtstrom nötig
   - Mit 4 AA-Batterien (2000–2500 mAh) sollte es reichen, aber nicht gemütlich
   - Daher: **9V-Block ist zu schwach!** (gibt nur 200–300 mA)

3. **Wärmeverlust**
   - Bei hohem Strom wird das IC warm
   - Kein eingebauter Kühlkörper

#### Alternative: Zwei L298N-Module (2 Kanäle each)

```
❌ Nachteile:
- Zwei separate Module nötig
- Komplexere Verdrahtung
- Mehr Platz nötig
- Höhere Kosten insgesamt

✅ Vorteile:
- Höherer Strom pro Kanal (2 A statt 500 mA)
- Einfachere Pin-Steuerung (EN + IN1/IN2 direkt)
```

**Wir haben uns für L293D entschieden**, weil:
- Platz-Effizienz (ein Shield, nicht zwei Module)
- AFMotor-Bibliothek ist fertig
- Für unser RC-Auto mit 4 AA-Batterien reicht die Stromstärke

---

### 3.4 Gleichstrommotoren: Getriebemotoren

#### Warum Getriebemotoren (mit Zahnrädern)?

```
❌ Gleichstrom-Motor (nackt)
   - Hohe RPM (~3000–10000)
   - Niedriges Drehmoment (wenig Kraft)
   → RC-Auto würde sich totdrehen, keine Zugkraft

✅ Getriebemotor
   - Niedriger RPM durch internes Zahnrad-Verhältnis (~50–500 RPM)
   - Hohes Drehmoment (kann Auto bewegen)
   - Schub ist gleichmäßig
```

#### Spezifikation der gewählten Motoren

**90°-Zahnräder (Standard für RC-Autos):**
- **Typ:** Gleichstrom-Getriebemotor (DC Gear Motor)
- **Spannung:** 3–6 V (oder 6–12 V, je nach Modell)
- **RPM:** 100–500 RPM (abhängig von Getriebe-Verhältnis)
- **Drehmoment:** 0,5–2 Nm (ausreichend für 200 g RC-Auto)

#### Vorteile

1. **Hohe Kraft bei niedriger Drehzahl**
   - Perfekt für Rad-Antrieb (brauchen hohe Zugkraft, nicht hohe RPM)

2. **Kompakt**

3. **Reversierbar**
   - Durch Spannungs-Richtung läuft Motor vorwärts oder rückwärts
   - Ideal für Panzer-Lenkung (Seiten gegeneinander drehen)

4. **Kostengünstig**
   - €5–10 pro Motor

#### Nachteile

1. **Zahnräder können verschleißen**
   - Nach 1000+ Betriebsstunden möglicherweise Spielraum
   - Für Schulprojekt: kein Problem

2. **Reibung durch Getriebe**
   - Etwas Energieverlust (aber unvermeidlich)

#### Motorenanzahl: Warum 4 statt 2?

```
Option A: 2 Motoren (links & rechts)
- ✅ Einfacher (Standard RC-Auto-Setup)
- ❌ Nur 2-Rad-Antrieb (Vorder- oder Hinterrad)
- ❌ Lenkung braucht Servo (kompliziert)

Option B: 4 Motoren (alle Räder)
- ✅ Alle Räder angetrieben (4WD — better traction)
- ✅ Panzer-Lenkung möglich (keine Servo nötig)
- ✅ Symmetrische Kraft auf allen Rädern
- ❌ 2× Stromverbrauch (aber unser Shield hält das)
- ❌ Komplexerer Arduino-Sketch
```

**Wir haben 4 Motoren gewählt**, weil:
1. L293D-Shield hat 4 Kanäle (würde ungenutzt bleiben mit nur 2 Motoren)
2. Panzer-Lenkung braucht keine Servo (weniger Hardware)
3. 4WD ist stabiler auf unebenem Untergrund

---

### 3.5 BLE-Modul: CC2541 / HM-10 statt klassisches Bluetooth

#### Warum BLE (Bluetooth Low Energy)?

```
                    BLE                  Klassisches Bluetooth
┌────────────────────────────────┬──────────────────────────────┐
│ Standard          │ 4.0 LE      │ 2.0 (SPP - Serial Port Pr.) │
│ Stromverbrauch    │ Sehr niedrig│ Höher                       │
│ macOS Support     │ Nativ/stabil│ Anfällig für Abbrüche       │
│ Profile           │ GATT        │ SPP (Serial)                │
│ Linux Support     │ Gut         │ Gut                         │
│ Geräte-Erkennung  │ CoreBluetooth│ /dev/rfcomm               │
│ Python Support    │ bleak       │ pyserial + rfcomm           │
└────────────────────────────────┴──────────────────────────────┘
```

#### Vorteile von BLE

1. **Stabil auf macOS 15 Sequoia**
   - Apple hat klassisches Bluetooth/SPP reduziert
   - BLE ist der empfohlene Standard
   - Keine Verbindungsabbrüche (erleben wir nicht)

2. **Niedriger Stromverbrauch**
   - Ideal für batteriebetriebene Geräte
   - Das Auto läuft auf 4 AA-Batterien — jede Milliampere zählt

3. **CoreBluetooth auf macOS**
   - Native Betriebssystem-API (nicht über `/dev/rfcomm`)
   - Zuverlässiger als klassisches BT

4. **Moderne Hardware**
   - CC2541 / HM-10 sind immer noch aktuell
   - Guter Support in der Maker-Community

#### Nachteile von BLE

1. **Nicht in klassischen Bluetooth-Einstellungen sichtbar**
   - `/dev/cu.Bluetooth-Incoming-Port` erscheint nicht
   - Manuelles Pairing wie bei klassischem BT nicht möglich
   - Python muss über GATT-Charakteristiken sprechen (komplexer)

2. **Mehr Code nötig**
   - Klassisches SPP: `pyserial` genügt
   - BLE: `bleak` (async/await, komplexer API)

3. **Service/Charakteristik-UUIDs kennen müssen**
   - FFE0 (Service), FFE1 (Charakteristik) müssen fest codiert sein
   - Weniger flexibel als SPP

#### Alternative: Klassisches Bluetooth (HC-05)

Würde funktionieren, **aber:**
- ❌ Auf macOS 15 anfällig für Verbindungsabbrüche
- ❌ Höherer Stromverbrauch
- ❌ Weniger zukunftsfähig

**Wir haben BLE gewählt**, weil macOS 15 es braucht.

---

### 3.6 Stromversorgung: 4 AA-Batterien statt 9V-Block

#### Das ursprüngliche Problem

Einkaufsliste sagte: **9V-Block für Motoren**

Realität nach erstem Test:
- ❌ 9V-Block liefert nur 200–300 mA
- ❌ 4 Motoren brauchen zusammen 500 mA–2 A
- ❌ Unter Last bricht die Spannung ein
- ❌ Auto "zuckelt" statt zu fahren

#### Warum 4 AA-Batterien besser sind?

| Aspekt | 9V-Block | 4 AA-Batterien | LiPo |
|---|---|---|---|
| **Spannung** | 9 V | 4,8–6 V (4×1,2–1,5 V) | 7,4 V (2S LiPo) |
| **Kapazität (mAh)** | 300–600 | 2000–3000 | 1000–2000 |
| **Max. Strom** | 200–300 mA | 1000–3000 mA | 3000–5000 mA |
| **Kosten** | €2–3 | €4–6 (Batterien) | €10–15 |
| **Verfügbarkeit** | Überall | Überall | Fachhandel |
| **Sicherheit** | Unkritisch | Unkritisch | Braucht Lader |

#### Vorteile von AA-Batterien

1. **Hohe Stromstärke**
   - 4 AA-Batterien parallel liefern locker 2–3 A
   - Motoren laufen kraftvoll, nicht schwach

2. **Lange Laufzeit**
   - 2000–3000 mAh bei 1–2 A Strom = 1–3 Stunden Fahrtdauer
   - 9V-Block schafft 30–60 Minuten

3. **Preis**
   - AA-Batterien sind überall €0,50–1 pro Stück
   - Wiederaufladbar (NiMH) möglich

4. **Einfacher Austausch**
   - Keine Lader nötig (nur Batteriegehäuse)
   - Im Notfall kann jeder AA-Batterien kaufen

#### Alternative: LiPo-Akku

**Vorteile:**
- ✅ Höhere Energiedichte
- ✅ Bessere Stromstärke
- ✅ Leichter als AA-Batterien

**Nachteile:**
- ❌ Spezieller LiPo-Lader nötig (~€15)
- ❌ Brandgefahr bei unsachgemäßer Behandlung
- ❌ Lagern erfordert Vorsicht (Überlastung, Tiefentladung)
- ❌ Teurer in der Anschaffung

**Für Schulprojekt:** 4 AA-Batterien sind praktischer.

---

### 3.8 Zusammenfassung: Hardware-Entscheidungen

| Komponente | Gewählt | Grund |
|---|---|---|
| **EEG-Headset** | MindFlex | Kostengünstig, einfaches Protokoll, Community-Support |
| **EEG-Arduino** | Uno | Standard, Brain-Library verfügbar |
| **Auto-Arduino** | Duemilanove | Kompatibel mit L293D-Shield |
| **Motor-Shield** | L293D (HW-130) | 4 Kanäle, AFMotor-Library, Platz-effizient |
| **Motoren** | Getriebemotoren | Hohes Drehmoment, Panzer-Lenkung möglich |
| **Motor-Anzahl** | 4 Stück | L293D hat 4 Kanäle, 4WD = stabiler |
| **Funk** | BLE | Stabil auf macOS 15, niedriger Stromverbrauch |
| **Stromversorgung** | 4 AA-Batterien | Genug Strom für Motoren, lange Laufzeit |

**Kernentscheidung:** Alle Komponenten sind aufeinander abgestimmt — kleine, unabhängig funktionierende Einheiten, die zusammen ein robustes System bilden.

---

## 4. Arduino-Sketches

### EEG-Arduino (Uno): `mindflex_eeg.ino`

**Aufgabe:** Liest ThinkGear-Rohsignale vom Headset und gibt eine CSV-Zeile aus

**Code-Struktur:**
```cpp
Brain brain(RX, TX);  // Initialisiert ThinkGear-Modul

void setup() {
    Serial.begin(9600);
}

void loop() {
    if (brain.update()) {  // Neue Daten vom Headset?
        Serial.println(...);  // CSV: SignalQuality,Attention,Meditation,Delta,...
    }
}
```

**CSV-Format:**
```
SignalQuality,Attention,Meditation,Delta,Theta,LowAlpha,HighAlpha,LowBeta,HighBeta,LowGamma,HighGamma
```

**Wichtig:** Headset ausschalten, bevor du den Sketch hochlädst (sonst stört der Datenstrom auf RX den Upload).

**Speicherort:** `~/Documents/Arduino/mindflex_eeg/mindflex_eeg.ino`

**Hochladen:**
```bash
~/.local/bin/arduino-cli compile --fqbn arduino:avr:diecimila:cpu=atmega328 ~/Documents/Arduino/mindflex_eeg/
~/.local/bin/arduino-cli upload -p /dev/cu.usbmodem141011 --fqbn arduino:avr:diecimila:cpu=atmega328 ~/Documents/Arduino/mindflex_eeg/
```

---

### Auto-Arduino (Duemilanove): `rc_car_4wd.ino`

**Aufgabe:** Empfängt Fahrbefehle (`F`, `B`, `L`, `R`, `S`) über BLE/SoftwareSerial und steuert 4 Motoren

**Code-Struktur:**
```cpp
#include <AFMotor.h>

AF_DCMotor motor1(1);  // M1-Klemme
AF_DCMotor motor2(2);  // M2-Klemme
AF_DCMotor motor3(3);  // M3-Klemme
AF_DCMotor motor4(4);  // M4-Klemme

SoftwareSerial ble(10, A0);  // RX=Pin10, TX=A0 (ungenutzt)

void setup() {
    Serial.begin(9600);
    ble.begin(9600);
}

void loop() {
    if (ble.available()) {
        char cmd = ble.read();
        switch(cmd) {
            case 'F': moveForward(); break;
            case 'B': moveBackward(); break;
            case 'L': turnLeft(); break;
            case 'R': turnRight(); break;
            case 'S': stop(); break;
            case 'T': testMotors(); break;  // Alle Motoren einzeln testen
        }
    }
    
    // Sicherheits-Watchdog: Nach 1s ohne Befehl stoppen
    if (millis() - lastCommand > 1000) {
        stop();
    }
}

void moveForward() {
    motor1.setSpeed(200); motor1.run(FORWARD);
    motor2.setSpeed(200); motor2.run(FORWARD);
    motor3.setSpeed(200); motor3.run(FORWARD);
    motor4.setSpeed(200); motor4.run(FORWARD);
}

void turnLeft() {
    motor1.setSpeed(255); motor1.run(BACKWARD);  // Rechts zurück
    motor2.setSpeed(255); motor2.run(FORWARD);   // Links vorwärts
    motor3.setSpeed(255); motor3.run(BACKWARD);  // Rechts zurück
    motor4.setSpeed(255); motor4.run(FORWARD);   // Links vorwärts
}

// ... analog turnRight(), moveBackward(), stop() ...
```

**Besonderheiten:**
- **4 Motoren parallel:** Alle vier Motoren bekommen die gleiche Geschwindigkeit
- **Panzer-Lenkung:** Drehen auf der Stelle (LEFT/RIGHT drehen beide Seiten gegeneinander)
- **Watchdog:** Stoppt nach 1 Sekunde ohne Signal (Sicherheit)
- **INVERT-Schalter:** Falls Motoren rückwärts drehen, einfach auf `true` setzen

**Speicherort:** `~/Documents/Arduino/rc_car_4wd/rc_car_4wd.ino`

**Hochladen:**
```bash
~/.local/bin/arduino-cli compile --fqbn arduino:avr:diecimila:cpu=atmega328 ~/Documents/Arduino/rc_car_4wd/
~/.local/bin/arduino-cli upload -p /dev/cu.usbserial-A6008mgO --fqbn arduino:avr:diecimila:cpu=atmega328 ~/Documents/Arduino/rc_car_4wd/
```

---

## 4. Python-Software (Klassifikation & GUI)

**Speicherort:** `~/Downloads/MindFlex_BCI_Projekt/`

### 4.1 Architektur

```
main.py
    |
    +---> SerialReceiver (Thread)  liest vom EEG-Arduino
    |
    +---> BrainProcessor
    |       |
    |       +---> FeatureExtractor   (5-Sekunden-Fenster)
    |       |
    |       +---> BCIClassifier      (trainiert/lädt ML-Modell)
    |       |
    |       +---> MainWindow (PyQt5) zeigt GUI
    |
    +---> BleCarController (asyncio-Thread)  sendet an Auto-Arduino
```

### 4.2 Datenfluss im Detail

**1. EEG-Empfang** (`serial_receiver.py`)

```python
class SerialReceiver:
    def __init__(self, port, baudrate=9600):
        self.serial = Serial(port, baudrate)
    
    def read_line(self):
        # Blockiert, bis eine komplette CSV-Zeile kommt
        # Format: SignalQuality,Attention,Meditation,Delta,...
        line = self.serial.readline().decode('utf-8').strip()
        return self._parse_csv(line)
```

- Läuft in eigenem Thread
- Versucht bei Fehler automatisch neu zu verbinden
- Sucht Port automatisch oder nutzt `MINDFLEX_EEG_PORT`

**2. Signalvalidierung** (`brain_processor.py`)

```python
class BrainProcessor:
    def process(self, data):
        if data['signal_quality'] == 200:
            # Signal verloren (kein Hautkontakt)
            return None  # Ignorieren!
        
        # Gültige Daten in 60-Sekunden-Ringpuffer
        self.buffer.append(data)
```

- Verwirft Pakete mit `signal_quality == 200` (ThinkGear-Konvention für "kein Signal")
- Puffert die letzten 60 Sekunden in Ring-Buffer
- Keine GUI-Updates, keine Fahrbefehle bei ungültigem Signal

**3. Feature-Extraktion** (`feature_extractor.py`)

```python
class FeatureExtractor:
    def extract_features(self, window):
        # Zeitfenster: 5 Sekunden Daten
        features = {}
        
        for band in ['Attention', 'Meditation', 'Delta', 'Theta', ...]:
            values = [sample[band] for sample in window]
            features[f'{band}_mean'] = np.mean(values)
            features[f'{band}_max'] = np.max(values)
            features[f'{band}_min'] = np.min(values)
            features[f'{band}_std'] = np.std(values)
        
        # Abgeleitete Features
        features['beta_alpha_ratio'] = total_beta / total_alpha
        features['attention_meditation_trend'] = trend(attention_values)
        
        return features
```

- Berechnet Mittelwert, Max, Min, Standardabweichung über **alle** EEG-Bänder
- Gleiche Feature-Extraktion beim Training und bei Live-Vorhersage (wichtig!)

**4. Machine Learning** (`classifier.py`)

```python
class BCIClassifier:
    def train(self, training_data):
        # Trainiert 3 Modelle
        models = {
            'decision_tree': DecisionTreeClassifier(),
            'random_forest': RandomForestClassifier(n_estimators=100),
            'knn': KNeighborsClassifier(n_neighbors=5)
        }
        
        # Test-Split: 80/20
        X_train, X_test, y_train, y_test = train_test_split(X, y, test_size=0.2)
        
        # Training + Evaluierung
        best_model = None
        best_accuracy = 0
        for name, model in models.items():
            model.fit(X_train, y_train)
            accuracy = model.score(X_test, y_test)
            if accuracy > best_accuracy:
                best_model = model
                best_accuracy = accuracy
        
        # Speichern des besten Modells (neu trainiert auf **allen** Daten)
        best_model.fit(X, y)
        joblib.dump(best_model, 'trained_model.pkl')
        
        return best_model
    
    def predict(self, features):
        # Live-Vorhersage
        model = joblib.load('trained_model.pkl')
        label = model.predict([features])
        confidence = model.predict_proba([features])
        return label, confidence
```

- Vergleicht Decision Tree, Random Forest, KNN
- Bestes Modell wird neu auf **allen** Daten trainiert (nicht nur Train-Set)
- Wird beim Start automatisch geladen

**5. Fahrzeugkontrolle** (`ble_car_controller.py`)

```python
class BleCarController:
    async def send_label(self, label):
        """Sendet einen Fahrbefehl (nur bei Änderung)"""
        if label != self.last_command:
            char_code = self._label_to_char(label)  # F / B / L / R / S
            await self.client.write_gatt_char(UUID, char_code.encode())
            self.last_command = label
    
    async def heartbeat(self):
        """Wiederholt den Befehl alle 0,4 Sekunden (Watchdog-Reset)"""
        while True:
            if self.last_command:
                await self.send_label(self.last_command)
            await asyncio.sleep(0.4)  # BleConfig.resend_interval
```

- **Deduplizierung:** Sendet Befehl nur bei Änderung
- **Heartbeat:** Wiederholt aktiven Befehl alle 0,4 Sekunden, sonst stoppt der Arduino nach 1s
- Asynchron (asyncio), weil BLE auf macOS über CoreBluetooth läuft

**6. Trainingsmodus** (`trainer.py`)

```python
class TrainingSession:
    def record(self, label, duration_seconds=10):
        """Nimmt Daten für 10 Sekunden unter Label 'label' auf"""
        start_time = time.time()
        collected = []
        
        while time.time() - start_time < duration_seconds:
            if self.processor.has_valid_signal():
                sample = self.processor.get_latest_sample()
                collected.append((sample, label))
        
        # Append to training_data.csv
        with open('training_data.csv', 'a') as f:
            for sample, lbl in collected:
                f.write(f"{sample},{lbl}\n")
```

- Nutzer wählt Label, drückt "Start Recording", denkt 10 Sekunden an den Fahrbefehl
- Alle gültigen EEG-Samples landen mit diesem Label in `training_data.csv`
- CLI-Modus: `python main.py --mode train`
- GUI-Modus: Button in der Oberfläche

**7. GUI** (`visualizer.py`, PyQt5 + pyqtgraph)

```python
class MainWindow(QMainWindow):
    def __init__(self):
        super().__init__()
        
        # Status-Ampel
        self.status_light = CircleLight()  # Rot=kein Signal, Gelb=schwach, Grün=gut
        
        # Live-Graphen (letzten 60 Sekunden)
        self.plot_widget = pyqtgraph.PlotWidget()
        self.plot_curves = {}
        for band in BANDS:
            self.plot_curves[band] = self.plot_widget.plot(name=band)
        
        # Vorhersage-Pfeil (grün=sicher, gelb=unsicher)
        self.prediction_arrow = RotatingArrow()
        
        # Buttons
        self.btn_start_training = QPushButton("Training starten")
        self.btn_retrain = QPushButton("Modell neu trainieren")
        self.btn_load_model = QPushButton("Letztes Modell laden")
        self.btn_export = QPushButton("Trainingsdaten exportieren")
    
    def update_ui(self):
        """Wird ~20 Hz aufgerufen"""
        # Graphen aktualisieren
        for band in BANDS:
            values = [s[band] for s in self.processor.buffer]
            self.plot_curves[band].setData(values)
        
        # Vorhersage aktualisieren
        if self.processor.has_valid_signal():
            label, confidence = self.classifier.predict(...)
            self.prediction_arrow.set_direction(label)
            self.prediction_arrow.set_confidence(confidence)
        
        # Status-Ampel aktualisieren
        quality = self.processor.get_signal_quality()
        self.status_light.set_color(quality_to_color(quality))
```

- Update-Rate: ~20 Hz
- Graphen zeigen letzte 60 Sekunden
- Vorhersage-Pfeil dreht sich (rot/gelb = Richtung + Konfidenz)
- Aufnahme & Training in eigenen Threads (GUI friert nicht ein)

---

## 5. Trainingsdaten & Modell

### Datenstruktur

**`training_data.csv`** — wächst beim Training:

```
signal_quality,attention,meditation,delta,theta,low_alpha,high_alpha,low_beta,high_beta,low_gamma,high_gamma,label
200,40,50,5000,3000,2000,1500,1200,1000,800,600,FORWARD
200,38,52,4900,2900,1900,1400,1100,950,750,580,FORWARD
0,42,48,5100,3200,2100,1600,1300,1100,850,650,STOP
...
```

- Jede Zeile = ein EEG-Sample (ausgegeben vom Arduino)
- Label = der Fahrbefehl, den der Nutzer dachte
- Gleiche Struktur beim Training und bei Live-Vorhersage (wichtig!)

### Datenvorbereitung

**Stand 2026-08-15:**
- Alte Daten (2 Klassen) gelöscht
- `trained_model_alt_2klassen.pkl` zum Vergleich archiviert
- **Neue Daten nötig für:** `LEFT`, `RIGHT`, sowie ausgeglichene Samples für `FORWARD` und `STOP`

**Aufzeichnungs-Richtlinie:**
```
Für jede Klasse ungefähr gleich lange aufzeichnen:
- FORWARD: ~30 Sekunden
- BACKWARD: ~30 Sekunden
- LEFT: ~30 Sekunden
- RIGHT: ~30 Sekunden
- STOP: ~30 Sekunden
```

Das verhindert, dass das Modell eine überrepräsentierte Klasse bevorzugt.

### Trainingsbefehl

```bash
# Interaktiv Daten sammeln
cd ~/Downloads/MindFlex_BCI_Projekt
python3 main.py --mode train

# Ohne Aufnahme, nur Modell neu trainieren
python3 main.py --mode retrain

# Oder über die GUI: Buttons "Training starten" + "Modell neu trainieren"
```

### Modell-Speicherort

```
~/Downloads/MindFlex_BCI_Projekt/trained_model.pkl
```

Wird beim Programmstart automatisch geladen. Falls nicht vorhanden, verwendet das System ein Dummy-Modell.

---

## 6. Bluetooth & Funk-Integration

### BLE-Module

**Hardware:**
- Typ: CC2541 / HM-10 / AT-09 / MLT-BT05 (alle kompatibel)
- Standard: Bluetooth 4.0 Low Energy (nicht klassisches Bluetooth 2.0)
- Baud-Rate: 9600
- Datendurchsatz: unbedenklich für Fahrbefehle

**Warum BLE?**
- Stabil auf macOS 15 Sequoia
- Klassisches SPP (HC-05) macht dort Verbindungsabbrüche
- Native macOS-Unterstützung über CoreBluetooth
- Energie-effizient

### BLE-Service & Charakteristik

```
Service:     FFE0
Characteristic: FFE1

Was du schreibst -> kommt am TXD-Pin heraus
```

Im Python-Code:

```python
from bleak import BleakClient

uuid_service = "0000ffe0-0000-1000-8000-00805f9b34fb"
uuid_char = "0000ffe1-0000-1000-8000-00805f9b34fb"

async with BleakClient(address) as client:
    await client.write_gatt_char(uuid_char, b"F")  # 'F' für Forward
```

### Modul-Adresse ermitteln

```bash
python3 ble_scan.py
```

Zeigt alle verfügbaren BLE-Module. **Wichtig:** Mit ausgeschaltetem Auto (sonst sind beide Module nicht auseinanderzuhalten).

Adresse setzen:

```bash
MINDFLEX_CAR_BLE_ADDRESS=12:34:56:78:9A:BC python3 main.py
```

**Jeder Mac braucht eine andere UUID!** Auf einem neuen Rechner neu ermitteln.

### Test ohne Auto

```bash
# Modul suchen
python3 ble_scan.py

# F/L/R/B/S einmal senden
python3 ble_test.py

# Controller mit Befehlswiederholung testen
python3 ble_controller_test.py
```

---

## 7. Diagnose & Fehlerbehandlung

### Ports anzeigen

```bash
ls /dev/cu.*
```

Beispiel-Ausgabe:
```
/dev/cu.usbmodem141011    # Arduino Uno (EEG)
/dev/cu.usbserial-A6008mgO  # Arduino Duemilanove (USB, nur beim Upload)
/dev/cu.Bluetooth-Incoming-Port  # klassisches Bluetooth (nicht relevant)
```

### Seriellen Monitor öffnen

```bash
# Für Duemilanove (Auto-Arduino)
~/.local/bin/arduino-cli monitor -p /dev/cu.usbserial-A6008mgO

# Für Uno (EEG-Arduino) — nur wenn kein Python läuft!
~/.local/bin/arduino-cli monitor -p /dev/cu.usbmodem141011
```

**Wichtig:** Nur ein Programm kann einen Port gleichzeitig öffnen. Wenn Python läuft, kann der IDE-Monitor nicht auf dem EEG-Port zugreifen.

### Aktuelles Log anzeigen

```bash
cd ~/Downloads/MindFlex_BCI_Projekt
tail -f mindflex_bci.log
```

### Umgebungsvariablen für Debugging

```bash
# Fester EEG-Port
MINDFLEX_EEG_PORT=/dev/cu.usbmodem141011 python3 main.py

# Fester Auto-Port (USB statt BLE)
MINDFLEX_CAR_TRANSPORT=serial MINDFLEX_CAR_PORT=/dev/cu.usbserial-A6008mgO python3 main.py

# Nur bestimmte Labels aktiv
MINDFLEX_ACTIVE_LABELS="STOP,FORWARD,LEFT" python3 main.py

# EEG per Funk statt USB
MINDFLEX_EEG_TRANSPORT=ble MINDFLEX_EEG_BLE_ADDRESS=12:34:56:78:9A:BC python3 main.py
```

---

## 10. Steuerungskonzept: Panzer-Lenkung

### Vier Fahrbefehle

```
FORWARD   Beide Seiten vorwärts
BACKWARD  Beide Seiten rückwärts
LEFT      Linke Seite vorwärts, rechte Seite rückwärts → Drehung auf der Stelle
RIGHT     Rechte Seite vorwärts, linke Seite rückwärts → Drehung auf der Stelle
STOP      Alle Motoren aus
```

### Warum kein klassisches Lenken?

- RC-Autos haben üblicherweise ein Servo-Lenkrad
- Unser Auto hat **keine Servo** — dafür sind die Pins am Shield belegt
- Mit vier Motoren können wir "Panzer-Stil" lenken: Jede Seite separat ansteuern

### Motor-Zuordnung

```
        vorne
M2 (li)  []  M1 (re)
M4 (li)  []  M3 (re)
        hinten
```

- **Linke Seite:** M2 (vorne) + M4 (hinten) immer synchron
- **Rechte Seite:** M1 (vorne) + M3 (hinten) immer synchron

### Drehgeschwindigkeit

```python
TURN_SPEED = 255  # Volle Kraft beim Drehen
FORWARD_SPEED = 200  # Etwas weniger beim Geradeausfahren
```

Beim Drehen schleifen alle Räder seitlich über den Boden — das braucht mehr Drehmoment.

---

## 11. Bekannte Probleme & Lösungen

### Problem 1: Port-Autoerkennung funktioniert nicht

**Symptom:** `Kein serieller Port gefunden (hint='Arduino')`

**Ursache:** Der Duemilanove meldet sich über seinen FTDI-Chip als "FT232R USB UART", nicht als "Arduino". Die Erkennung sucht aber nach dem Substring "Arduino".

**Lösung:** Ports fest setzen:
```bash
MINDFLEX_EEG_PORT=/dev/cu.usbmodem141011 \
MINDFLEX_CAR_PORT=/dev/cu.usbserial-A6008mgO python3 main.py
```

Der Uno wird auf dieser Mac richtig erkannt, der Duemilanove nicht.

### Problem 2: Auto stoppt nach 1 Sekunde beim Fahren

**Symptom:** Auto fährt kurz und bleibt dann stehen, obwohl der Fahrbefehl unverändert ist

**Ursache:** Der Arduino-Sketch hat einen 1-Sekunden-Watchdog (Sicherheit). Python sendet einen Befehl aber nur, wenn er sich ändert (`last_command`-Deduplizierung). Bei dauerhaftem "FORWARD" kommt also nach der ersten Sekunde kein neuer Befehl → Arduino stoppt.

**Lösung:** Ein Heartbeat-Task wiederholt den Befehl alle 0,4 Sekunden:
```python
async def heartbeat(self):
    while True:
        if self.last_command:
            await self.send_label(self.last_command)
        await asyncio.sleep(0.4)
```

Die Deduplizierung bleibt — nur die Wiederholung greift.

### Problem 3: Der Sketch liest von der falschen Schnittstelle

**Symptom:** Keine Fahrbefehle ankommen, obwohl BLE verbunden ist

**Ursache:** Der Duemilanove hat nur eine Hardware-UART (Pin 0/1). Sie ist mit dem USB-Chip verbunden. Säße das HC-05 dort, wäre weder Sketch-Upload noch Debugging möglich. Der Sketch muss auf `SoftwareSerial` umgestellt werden.

**Lösung:** `SoftwareSerial(10, A0)` im Sketch verwenden:
```cpp
SoftwareSerial ble(10, A0);  // RX=Pin 10, TX=A0 (ungenutzt)

void setup() {
    Serial.begin(9600);      // USB
    ble.begin(9600);         // Bluetooth
}

void loop() {
    if (ble.available()) {
        char cmd = ble.read();
        // ...
    }
}
```

### Problem 4: L293D vs. L298N — Shield-Pinbelegung

**Symptom:** Motoren drehen nicht oder falsch nach Motor-Shield-Upgrade

**Ursache:** Der alte Sketch war für L298N-H-Brücke geschrieben (direkte Pinansteuerung). Das neue L293D-Shield nutzt ein Schieberegister und die `AFMotor`-Bibliothek.

**Lösung:** Motor-Teil mit `AFMotor` reschreiben:
```cpp
#include <AFMotor.h>

AF_DCMotor motor1(1);
AF_DCMotor motor2(2);
AF_DCMotor motor3(3);
AF_DCMotor motor4(4);

void moveForward() {
    motor1.setSpeed(200);
    motor1.run(FORWARD);
    // ... analog für andere Motoren
}
```

---

## 12. Schritt-für-Schritt: Von der Installation zum ersten Fahrt

### Schritt 1: Voraussetzungen

```bash
# Python 3.8+
python3 --version

# Arduino CLI installiert?
~/.local/bin/arduino-cli version

```

### Schritt 2: Pythonpakete installieren

```bash
cd ~/Downloads/MindFlex_BCI_Projekt
pip3 install -r requirements.txt
```

**Dateiinhalt `requirements.txt`:**
```
pyserial==3.5
scikit-learn==1.3.0
numpy==1.24.0
PyQt5==5.15.9
pyqtgraph==0.13.3
bleak==0.20.0  # BLE
```

### Schritt 3: Arduino-Sketches hochladen

**EEG-Arduino (Uno):**
```bash
~/.local/bin/arduino-cli upload \
    -p /dev/cu.usbmodem141011 \
    --fqbn arduino:avr:diecimila:cpu=atmega328 \
    ~/Documents/Arduino/mindflex_eeg/
```

**Auto-Arduino (Duemilanove):**
```bash
~/.local/bin/arduino-cli upload \
    -p /dev/cu.usbserial-A6008mgO \
    --fqbn arduino:avr:diecimila:cpu=atmega328 \
    ~/Documents/Arduino/rc_car_4wd/
```

### Schritt 4: Headset testen

```bash
# Seriellen Monitor öffnen (Uno)
~/.local/bin/arduino-cli monitor -p /dev/cu.usbmodem141011
```

Sollte CSV-Zeilen ausgeben. Wenn nicht: Headset an, Kontakt auf Stirn prüfen.

### Schritt 5: BLE-Modul-Adresse ermitteln

```bash
cd ~/Downloads/MindFlex_BCI_Projekt
python3 ble_scan.py
```

Notiere die Adresse des Auto-Moduls (CC2541 / HM-10).

### Schritt 6: Trainingsdaten sammeln

```bash
cd ~/Downloads/MindFlex_BCI_Projekt
python3 main.py --mode train
```

Folge den Anweisungen:
1. Wähle ein Label (z. B. "FORWARD")
2. Denke 10 Sekunden an Vorwärtsfahrt
3. Wiederhöle für alle 5 Labels, jeweils ~30 Sekunden

→ Schreibt `training_data.csv`

### Schritt 7: Modell trainieren

```bash
cd ~/Downloads/MindFlex_BCI_Projekt
python3 main.py --mode retrain
```

Wertet `training_data.csv` aus, trainiert 3 Modelle, speichert das beste.

### Schritt 8: GUI starten & fahren

```bash
MINDFLEX_CAR_BLE_ADDRESS=<UUID> python3 main.py
```

GUI zeigt:
- Status-Ampel (Signalqualität)
- Live-Graphen
- Vorhersage mit Konfidenz-Pfeil
- Buttons zum Retraining

Denke an Fahrtrichtungen → Auto fährt!

---

## 13. Bekannte Einschränkungen

### 1. EEG-Hardware ist begrenzt

**MindFlex misst mit nur einer Elektrode (Fp1, Stirn).** Der Unterschied zwischen "denk LEFT" und "denk RIGHT" entsteht aber über dem motorischen Kortex (C3/C4 — beide Seiten). Die Elektrode sitzt dort gar nicht. Es ist deshalb gut möglich, dass LEFT/RIGHT im Signal nicht zu trennen sind.

**Workaround:** Umgebungsvariable auf 3 Labels reduzieren:
```bash
MINDFLEX_ACTIVE_LABELS="STOP,FORWARD,LEFT" python3 main.py
```

BACKWARD bleibt in der Konfiguration erhalten und kann jederzeit reaktiviert werden.

### 2. ML-Modell braucht individuelle Trainingsdaten

Gehirnwellen sind sehr individuell. Ein Modell, das auf Moritz trainiert wurde, funktioniert möglicherweise nicht für Anna. Jede Person sollte eigene Trainingsdaten sammeln.

### 3. Signalqualität ist nicht garantiert

- Trockenelektrode benötigt guten Hautkontakt
- Haare unter der Elektrode verschlechtern den Kontakt
- Bei Bewegung Artefakte möglich
- ThinkGear-Chip filtert aggressiv (keine Rohdaten möglich)

### 4. RC-Auto reagiert asynchron

Durch BLE-Funklatenz und Arduino-Verarbeitung gibt es eine Verzögerung von ~100–200 ms. Das ist für ein RC-Auto akzeptabel, aber nicht ideal für präzise Steuerung.

---

## 14. Nächste Schritte & Verbesserungen

### Geplant

- [ ] Trainingsdaten für LEFT & RIGHT sammeln (alle 5 Labels gleich gewichtet)
- [ ] Modell-Genauigkeit mit nur 3 Labels vs. 4 Labels vs. 5 Labels vergleichen
- [ ] Latenzmessung (wie lange von "Gedanke" bis "Auto fährt"?)
- [ ] Architektur-Verbesserungen (z. B. LSTM für Zeitabhängigkeiten?)

### Optional

- **Servo-Lenk-Upgrade:** Klassisches Lenken statt Panzer-Stil (braucht neues Shield ohne Motor 4)
- **IMU-Integration:** Beschleunigungssensor + Gyroskop für stabilere Vorhersagen
- **Web-UI:** Statt PyQt5 → Browser-Oberfläche mit Flask/Dash
- **Multi-Person-Klassifikation:** Einzelnes Modell für mehrere Personen
- **Hyperparameter-Tuning:** GridSearch für beste ML-Parameter

---

## 15. Wichtige Referenzen & Dateien

| Datei | Zweck |
|---|---|
| `~/Downloads/MindFlex_BCI_Projekt/main.py` | Hauptprogramm |
| `~/Downloads/MindFlex_BCI_Projekt/training_data.csv` | Trainingsdaten (wächst beim Trainieren) |
| `~/Downloads/MindFlex_BCI_Projekt/trained_model.pkl` | Gespeichertes ML-Modell |
| `~/Documents/Arduino/mindflex_eeg/` | EEG-Arduino-Sketch |
| `~/Documents/Arduino/rc_car_4wd/` | Auto-Arduino-Sketch |
| `mindflex_bci.log` | Logs (im Projektordner) |
| `code/` | Versionsübersicht des Codes |

---

## 16. Zusammenfassung: Das System in einer Nutshell

```
┌─────────────────────────────────────────────────────────┐
│ 1. DU TRÄGST EIN EEG-HEADSET                            │
│    (NeuroSky MindFlex, eine Elektrode auf Fp1)          │
└─────────────────────────────────────────────────────────┘
        ↓ (seriell: USB oder BLE)
┌─────────────────────────────────────────────────────────┐
│ 2. ARDUINO UNO LIEST GEHIRNWELLEN                        │
│    (ThinkGear-Protokoll) → CSV-Zeile alle 500 ms        │
└─────────────────────────────────────────────────────────┘
        ↓
┌─────────────────────────────────────────────────────────┐
│ 3. PYTHON ANALYSIERT SIGNALE                            │
│    - Signalqualität prüfen                              │
│    - Features extrahieren (5 Sekunden-Fenster)          │
│    - ML-Modell vorhersagen (Decision Tree / RF / KNN)   │
│    - Label → Fahrbefehl (F/B/L/R/S)                     │
└─────────────────────────────────────────────────────────┘
        ↓ (BLE: Bluetooth Low Energy)
┌─────────────────────────────────────────────────────────┐
│ 4. ARDUINO DUEMILANOVE STEUERT AUTO                     │
│    - Empfängt Fahrbefehl über BLE                       │
│    - Weiterleitung zu L293D Shield                       │
│    - Shield steuert 4 Getriebemotoren                   │
└─────────────────────────────────────────────────────────┘
        ↓
┌─────────────────────────────────────────────────────────┐
│ 5. RC-AUTO FÄHRT!                                       │
│    (Panzer-Lenkung: Seiten unabhängig, Drehung Stelle) │
└─────────────────────────────────────────────────────────┘
```

---

**Zuletzt aktualisiert:** 2026-09-02

Weitere Details zu einzelnen Komponenten siehe verwandte Notizen und die Versionsübersicht des Codes.

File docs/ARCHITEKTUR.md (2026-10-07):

# Architektur

Wie das System aufgebaut ist, warum die Bauteile so gewählt wurden und was man über die
Grenzen wissen sollte. Stand: Software-Version 3.4.

**Inhalt**

1. [Überblick](#1-überblick)
2. [Hardware](#2-hardware)
3. [Arduino-Sketches](#3-arduino-sketches)
4. [Python-Anwendung](#4-python-anwendung)
5. [Training, Kalibrierung und Bewertung](#5-training-kalibrierung-und-bewertung)
6. [Bluetooth-Strecke](#6-bluetooth-strecke)
7. [Sicherheit](#7-sicherheit)
8. [Bauteilwahl im Vergleich](#8-bauteilwahl-im-vergleich)
9. [Grenzen](#9-grenzen)
10. [Fehlerbilder und Lösungen](#10-fehlerbilder-und-lösungen)

---

## 1. Überblick

```
MindFlex-Headset ──T-Pin──▶ Arduino Uno ──USB oder BLE──▶ Python (Mac)
                                                            │
                     Empfang → Vorverarbeitung → Merkmale → Klassifikation → GUI
                                                            │
RC-Auto ◀── L293D-Shield ◀── Arduino Duemilanove ◀──BLE─────┘  F / B / L / R / S
```

Zwei Arduinos, weil die beiden Aufgaben nichts miteinander zu tun haben: Der eine liest nur das
Headset aus, der andere setzt nur Fahrbefehle in Motorbewegung um. Die eigentliche Arbeit –
Merkmale berechnen, Modelle trainieren, vorhersagen – läuft in Python auf dem Rechner, denn
scikit-learn gibt es nicht für Mikrocontroller. So lassen sich alle drei Teile einzeln testen.

---

## 2. Hardware

### 2.1 EEG-Seite

| Bauteil | Aufgabe |
|---|---|
| MindFlex-Headset (Mattel) | Trockenelektrode auf der Stirn (Position Fp1), Referenz über Ohrclip |
| NeuroSky **TGAM**-Modul im Headset | ThinkGear-Chip: filtert das Rohsignal und liefert einmal pro Sekunde Signalqualität, Attention, Meditation und acht Bandleistungen |
| Arduino Uno (hier ein Funduino-Nachbau) | liest den T-Pin des TGAM über RX, gibt CSV-Zeilen aus |
| BLE-Modul CC2541 (HM-10-Klon), optional | funkt die CSV-Zeilen statt über USB |
| 9-V-Block mit Schalter | versorgt den Uno über den Rundstecker, wenn kein USB-Kabel steckt |

Verkabelung:

```
TGAM T-Pin   → Uno Pin 0 (RX)
TGAM GND     → Uno GND

nur für Funk:
BLE VCC      → 3,3V
BLE GND      → GND
BLE RXD      → Pin 1 (TX)
BLE TXD      → nicht angeschlossen
```

Alle Verbindungen sind direkt, ohne Widerstände – so ist das Headset aufgebaut und getestet.
Die Bibliothek liest den Chip und schreibt die fertigen Zeilen auf derselben Hardware-
Schnittstelle – Pin 0 ist Eingang, Pin 1 Ausgang, das stört sich nicht. Das Funkmodul hört
einfach mit, was ohnehin an Pin 1 hinausgeht.

### 2.2 Auto-Seite

| Bauteil | Aufgabe |
|---|---|
| Arduino Duemilanove (ATmega328P) | empfängt Fahrbefehle, steuert das Shield |
| L293D-Motor-Shield (HW-130) | vier H-Brücken, angesteuert über ein Schieberegister (74HC595) |
| 4 TT-Getriebemotoren mit Rädern | Allradantrieb, Lenkung wie bei einem Panzer |
| BLE-Modul CC2541 (HM-10-Klon) | Funkempfang |
| 9-V-Block | Stromversorgung des Autos |
| 3D-gedrucktes Chassis | [`hardware/chassis_car.stl`](../hardware/chassis_car.stl) |

Belegung am Shield:

```
            vorne
   M2 (links)   M1 (rechts)
   M3 (links)   M4 (rechts)
            hinten
```

Funkmodul am Duemilanove:

```
BLE TXD → Pin 10   (SoftwareSerial RX)
BLE RXD → Pin A0   (nur für den Rückkanal nötig)
BLE VCC → 3,3V,  GND → GND
```

Auch hier ohne Widerstände. Der Duemilanove hat keinen eigenen 3,3-V-Regler; die 3,3 V
kommen aus seinem USB-Chip FT232RL (höchstens etwa 50 mA). Für das Funkmodul reicht das.

**Nicht Pin 11 verwenden.** Viele Anleitungen legen das Funkmodul auf `SoftwareSerial(10, 11)`,
aber auf dem HW-130 ist Pin 11 der PWM-Ausgang von Motor 1. Belegt sind durch das Shield:

| Pins | Verwendung |
|---|---|
| 3, 5, 6, 11 | PWM für M2, M3, M4, M1 |
| 4, 7, 8, 12 | Schieberegister für alle Motoren |
| 9, 10 | Servo-Anschlüsse, frei solange kein Servo steckt |
| 2, 13, A0–A5 | frei |

Eine Übersicht als Bild: [`docs/images/wiring.svg`](images/wiring.svg). Die Einkaufsliste steht
in [`docs/TEILELISTE.md`](TEILELISTE.md).

---

## 3. Arduino-Sketches

Alle Sketches liegen unter [`MindFlex_BCI_Projekt/arduino/`](../MindFlex_BCI_Projekt/arduino).

### `mindflex_eeg.ino` (Uno)

- beruht auf dem Beispiel *BrainSerialTest* der
  [Arduino Brain Library](https://github.com/kitschpatrol/Brain)
- 9600 Baud, eine Zeile pro Sekunde:
  `SignalQuality,Attention,Meditation,Delta,Theta,LowAlpha,HighAlpha,LowBeta,HighBeta,LowGamma,HighGamma`
- `SignalQuality` zählt andersherum: 0 ist perfekter Kontakt, 200 gar keiner
- sendet zusätzlich alle 5 s eine Zeile `BAT,...` mit der Versorgungsspannung; die Python-Seite
  verwirft sie stillschweigend
- **Beim Hochladen** das Headset ausschalten oder die Leitung an Pin 0 abziehen, sonst stört
  der Datenstrom den Upload

### `rc_car_4wd.ino` (Duemilanove)

- braucht die *Adafruit Motor Shield Library* in **Version 1** (`AFMotor`)
- Befehle über Bluetooth oder den Seriellen Monitor:

| Zeichen | Wirkung |
|---|---|
| `F` | alle vier Räder vorwärts (Geschwindigkeit 200 von 255) |
| `B` | alle vier Räder rückwärts |
| `L` | links rückwärts, rechts vorwärts – dreht auf der Stelle nach links (255) |
| `R` | links vorwärts, rechts rückwärts – dreht nach rechts |
| `S` | Stopp |
| `1`–`4` | nur diesen Motor kurz laufen lassen |
| `T` | alle vier Motoren nacheinander testen |

- Drehen bekommt volle Kraft, weil die Räder dabei seitlich über den Boden schleifen
- jeder Motor hat einen eigenen Schalter `INVERT[]`, falls er verkehrt herum läuft; zum
  Einstellen das Auto aufbocken und mit `T` prüfen
- **Watchdog:** kommt 1 s lang kein Befehl, stoppen alle Motoren (siehe [Sicherheit](#7-sicherheit))

### `rc_car_test.ino`

Test ohne Motoren: zeigt im Seriellen Monitor, welcher Befehl über welchen Weg ankam und
welche Pegel die Motoren bekommen würden. Pin 13 leuchtet, solange ein Fahrbefehl aktiv ist.

---

## 4. Python-Anwendung

Ordner [`MindFlex_BCI_Projekt/`](../MindFlex_BCI_Projekt). Start mit `python main.py`.

### 4.1 Module

| Modul | Aufgabe |
|---|---|
| `main.py` | Einstieg, verdrahtet alles; Modi `run` (GUI), `train` (Konsole), `retrain` |
| `config.py` | alle Einstellungen an einer Stelle, überschreibbar per Umgebungsvariable |
| `serial_receiver.py` | liest CSV-Zeilen per USB, sucht den Port selbst, verbindet neu bei Abbruch |
| `ble_serial_receiver.py` | dasselbe über Bluetooth (bleak) |
| `brain_processor.py` | prüft die Signalqualität, hält die letzten 60 s in einem Ringpuffer |
| `feature_extractor.py` | berechnet 33 Merkmale aus einem 5-s-Fenster |
| `classifier.py` | bewertet drei Verfahren, speichert das beste, sagt vorher |
| `trainer.py` | nimmt Trainingsdaten auf, schreibt `training_data.csv` |
| `ble_car_controller.py` | sendet Fahrbefehle per Bluetooth, mit Wiederholung |
| `car_controller.py` | dasselbe per USB-Kabel, zum Testen |
| `visualizer.py`, `gui_*.py` | Oberfläche (PyQt5 + pyqtgraph) |
| `ble_scan.py`, `ble_test.py`, `ble_remote.py` | Hilfsprogramme: Module finden, Befehle testen, Auto per Tastatur fahren |

### 4.2 Datenfluss

1. **Empfang:** Jede Zeile wird in ein `EEGSample` zerlegt. Alpha, Beta und Gamma werden aus
   den Low- und High-Werten gemittelt. Zeilen, die durch ein verlorenes Funkpaket zerrissen
   sind, und `BAT`-Zeilen werden verworfen.
2. **Vorverarbeitung:** Ein Sample mit Signalqualität 200 („kein Kontakt“) aktualisiert nur die
   Verbindungsanzeige – keine Graphen, keine Vorhersage, kein Fahrbefehl. Gültige Samples landen
   im Ringpuffer. Kommt 3 s lang gar nichts mehr, gilt das Signal als tot.
3. **Merkmale:** Für sieben Größen (Attention, Meditation, Delta, Theta, Alpha, Beta, Gamma)
   je Mittelwert, Maximum, Minimum und Standardabweichung, dazu Beta/Alpha-Verhältnis, Änderung
   von Attention und Meditation und deren Mittel der letzten 5 s – zusammen 33 Werte. Training
   und Live-Betrieb benutzen exakt dieselbe Berechnung in derselben Reihenfolge.
4. **Vorhersage:** einmal pro Sekunde über das jüngste 5-s-Fenster; Ergebnis ist ein Befehl und
   eine Konfidenz.
5. **Fahren:** Das Label wird in ein Zeichen übersetzt (`STOP`→`S`, `FORWARD`→`F`, …) und nur
   gesendet, wenn die Fahrsperre aus ist.

### 4.3 Oberfläche

- Statuszeile: Signalqualität des Headsets in Prozent, Paketzähler, Verbindung zum Auto,
  Knopf „Neu verbinden“, Umschalter hell/dunkel
- EEG-Verlauf (logarithmische Skala) und eSense-Werte, Kacheln je Band, Aufzeichnung anhalten
- Fahren: Vorhersage mit Pfeil und Konfidenz, **Fahrsperre** (Standard: an), **Handbetrieb** mit
  W A S D oder Pfeiltasten
- Aufnehmen: Training, Kalibrierung, einfache Aufnahmen; Dialoge für Trainingsdaten, Rohdaten
  und die Verwechslungsmatrix
- Modell: Genauigkeit aller drei Verfahren und die Basisrate
- Profile: jede Person hat einen eigenen Ordner `profile/<name>/` mit `training_data.csv`,
  `trained_model.pkl` und `kalibrierung.json`

### 4.4 Wichtige Umgebungsvariablen

| Variable | Bedeutung | Standard |
|---|---|---|
| `MINDFLEX_EEG_TRANSPORT` | `seriell` oder `ble` | `seriell` |
| `MINDFLEX_EEG_PORT` | fester Port des Uno | automatisch |
| `MINDFLEX_EEG_BLE_ADDRESS` | Adresse des Headset-Funkmoduls | in `config.py` |
| `MINDFLEX_CAR_TRANSPORT` | `ble` oder `serial` | `ble` |
| `MINDFLEX_CAR_BLE_ADDRESS` | Adresse des Auto-Funkmoduls | in `config.py` |
| `MINDFLEX_CAR_PORT` | Port des Duemilanove bei `serial` | automatisch |
| `MINDFLEX_PROFIL` | Profil beim Start | `standard` |
| `MINDFLEX_ACTIVE_LABELS` | trainierte Befehle, z. B. `STOP,FORWARD,BACKWARD` | `STOP,FORWARD,BACKWARD` |

Unter macOS sind die Bluetooth-Adressen CoreBluetooth-UUIDs, die **auf jedem Rechner anders**
sind. Auf einem neuen Rechner mit `python3 ble_scan.py` neu ermitteln – dabei jeweils nur ein
Modul einschalten, denn beide bewerben denselben Dienst.

---

## 5. Training, Kalibrierung und Bewertung

### 5.1 Daten sammeln

- **Training:** Befehl wählen, Dauer wählen, aufnehmen. Jede Aufnahme wird ein eigener Block.
- **Kalibrierung:** ein fester Plan, in dem jede mögliche Reihenfolge der Befehle genau einmal
  vorkommt – bei drei Befehlen sechs Reihenfolgen, also 18 Blöcke à 15 s. So steht jeder Befehl
  gleich oft am Anfang und am Ende und folgt jedem anderen gleich oft; Ermüdung und
  Nachwirkungen verteilen sich gleichmäßig. Vor jedem Block sagt der Mac die Anweisung an, dann
  folgt eine nicht aufgezeichnete Wechselzeit von 3 s (Alpha fällt nach dem Augenöffnen erst
  nach 2–3 s ab), dann die Aufnahme, dann ein Endton.
  Damit lässt sie sich auch mit geschlossenen Augen befolgen. Die Ansage nutzt `say` und
  `afplay` und funktioniert deshalb nur auf dem Mac.
- Die Anweisungen sind je Profil einstellbar. Voreingestellt:

| Befehl | Anweisung | Was das Headset sieht |
|---|---|---|
| STOP | Augen zu | Alpha steigt deutlich (Berger-Effekt) |
| FORWARD | Augen auf | Alpha fällt |
| BACKWARD | Kopf schütteln oder Kiefer zusammenbeißen | Muskel- und Bewegungsartefakte in Beta/Gamma |

### 5.2 Modelle

Verglichen werden ein Entscheidungsbaum, ein Random Forest (100 Bäume) und k-nächste Nachbarn
(k = 5, mit vorgeschalteter Standardisierung in einer Pipeline, damit die großen Bandwerte die
Abstände nicht dominieren). Das beste Verfahren wird anschließend auf allen Daten neu trainiert
und im Profil gespeichert.

### 5.3 Ehrlich bewerten

Aus einer Aufnahme entstehen viele Fenster, die sich fast vollständig überlappen. Ein
Zufallssplit über einzelne Fenster würde praktisch dieselben Daten im Training und im Test
haben und viel zu gute Zahlen liefern.

Deshalb gilt:

- Bewertet wird mit `StratifiedGroupKFold`: Eine **ganze Aufnahme** liegt entweder im Training
  oder im Test. Dafür braucht jede Klasse mindestens zwei getrennte Aufnahmen; sonst fällt das
  Programm auf einen Zufallssplit zurück und warnt deutlich.
- Neben jeder Genauigkeit steht die **Basisrate** – wie gut man wäre, wenn man immer die
  häufigste Klasse rät.
- Die **Verwechslungsmatrix** beruht auf denselben zurückgehaltenen Aufnahmen.

Ergebnisse stehen in der [README](../README.md#ergebnisse).

---

## 6. Bluetooth-Strecke

Beide Funkmodule sind CC2541-Module (HM-10-Familie) mit **Bluetooth Low Energy**, kein
klassisches Bluetooth wie beim HC-05. Das hat Folgen:

- Sie erscheinen weder in den Bluetooth-Einstellungen von macOS noch als serieller Port.
- Python spricht sie über GATT an (Bibliothek `bleak`): Dienst `FFE0`, Charakteristik `FFE1`.
  Was man in die Charakteristik schreibt, gibt das Modul an seinem TXD-Pin aus – und umgekehrt.
- Processing kann kein BLE. Für den BrainGrapher gibt es deshalb `ble_bridge.py`, das die
  Zeilen über TCP (127.0.0.1:5204) an den Sketch weiterreicht.
- Ein Modul akzeptiert nur eine Verbindung gleichzeitig. Läuft `ble_bridge.py`, kann
  `main.py` nicht zum Headset verbinden.

---

## 7. Sicherheit

Ein Auto, das auf veralteten Daten weiterfährt, ist das größte Risiko. Darum mehrere Stufen:

| Stufe | Wo | Wirkung |
|---|---|---|
| Fahrsperre | GUI | beim Start an; Vorhersagen werden angezeigt, aber nicht gesendet |
| Kein Kontakt | Python | bei Signalqualität 200 keine Vorhersage und kein Fahrbefehl |
| Signal-Timeout | Python | 3 s ohne Paket → Signal gilt als tot |
| Befehlswiederholung | Python | der aktuelle Befehl wird alle 0,4 s wiederholt |
| Watchdog | Arduino | 1 s ohne Befehl → Motoren aus |
| Handbetrieb | GUI | fährt nur, solange die Taste gedrückt ist; Loslassen oder Fensterwechsel → Stopp |

Die Wiederholung und der Watchdog gehören zusammen: Python sendet einen Befehl sonst nur bei
Änderung. Ohne Wiederholung bliebe das Auto bei dauerhaftem FORWARD nach einer Sekunde stehen;
ohne Watchdog führe es nach einem Funkabbruch einfach weiter.

---

## 8. Bauteilwahl im Vergleich

### Headset

| | MindFlex | Muse | Emotiv EPOC | OpenBCI |
|---|---|---|---|---|
| Kanäle | 1 (Stirn) | 4 | 14 | 8–16 |
| Rohdaten | nein, nur Bandleistungen | ja | ja | ja |
| Preis | Spielzeug, gebraucht günstig | mittel | hoch | hoch |

Das MindFlex war verfügbar und günstig, und die Arduino Brain Library liest es ohne Aufwand
aus. Der Preis dafür: eine einzige Elektrode und eine Blackbox, die nur fertig berechnete
Werte liefert (siehe [Grenzen](#9-grenzen)).

### Motortreiber

Das L293D-Shield (HW-130) treibt vier Motoren getrennt (600 mA Dauerstrom je Kanal, 1,2 A
Spitze) und wird einfach aufgesteckt. Ein L298N-Modul kann mehr Strom, hat aber nur zwei
Kanäle – für vier Motoren bräuchte man zwei Module und deutlich mehr Verkabelung.

### Stromversorgung

Headset und Auto laufen jeweils mit einem 9-V-Block – leicht, überall erhältlich und schnell
gewechselt. Am Headset hängen nur der Uno und ein Funkmodul, dafür reicht er locker. Im Auto
treibt er zusätzlich vier Motoren an. Ein 9-V-Block liefert nur wenige hundert Milliampere; wenn
alle Motoren gleichzeitig anlaufen, sinkt seine Spannung, und die Fahrzeit ist begrenzt. Wer mehr
Kraft oder längere Fahrten braucht, kann auf AA-Zellen oder einen Akku umsteigen.

### Vier Motoren statt zwei

Mit vier einzeln angesteuerten Motoren braucht das Auto kein Lenkservo: Zum Drehen laufen die
beiden Seiten gegenläufig. Das nutzt alle vier Kanäle des Shields und ist auf unebenem Boden
stabiler.

---

## 9. Grenzen

- **Eine Elektrode auf der Stirn.** Die Vorstellung von Links- und Rechtsbewegungen entsteht
  über dem motorischen Kortex (C3/C4), dort misst das Headset nicht. LEFT und RIGHT sind deshalb
  im Code vorhanden, aber nicht aktiv.
- **Was zuverlässig funktioniert, ist physiologisch gut begründet:** Augen zu gegen Augen auf
  (Berger-Effekt). BACKWARD beruht auf einem Muskelsignal – kein EEG im engeren Sinn, aber
  bewusst steuerbar.
- **Attention und Meditation** sind Werte des Herstellers mit unbekannter Berechnung, keine
  Messgrößen.
- **Modelle sind persönlich.** Ein Modell funktioniert praktisch nur für die Person, mit deren
  Daten es trainiert wurde. Darum die Profile.
- **Trockenelektrode:** Haare, Schweiß und Bewegung verschlechtern den Kontakt.
- **Verzögerung:** Das 5-s-Fenster und die Vorhersage im Sekundentakt machen das Auto träge.
  Eine genaue Messung der Latenz steht noch aus.

---

## 10. Fehlerbilder und Lösungen

| Symptom | Ursache | Lösung |
|---|---|---|
| Upload auf den Uno schlägt fehl | Das Headset sendet in Pin 0 | Headset aus oder RX-Leitung abziehen |
| `Kein serieller Port gefunden` | Der Duemilanove meldet sich als „FT232R USB UART“, nicht als „Arduino“ | Port fest setzen: `MINDFLEX_CAR_PORT=...` |
| Auto fährt eine Sekunde und bleibt stehen | Watchdog greift, weil der Befehl nur bei Änderung gesendet wurde | Befehlswiederholung alle 0,4 s (ist eingebaut) |
| Fahrbefehle kommen nicht an | Funkmodul an der Hardware-UART statt an SoftwareSerial | Modul an Pin 10 / A0, siehe oben |
| Motor 1 und Bluetooth stören sich | Funkmodul an Pin 11 = PWM von Motor 1 | Pin A0 statt 11 |
| Ein Rad dreht falsch herum | Motor gespiegelt eingebaut oder verkehrt angeklemmt | `INVERT[]` im Sketch, mit `T` prüfen |
| „BLE verbindet nicht“ | `MINDFLEX_EEG_PORT` erzwingt den Kabelweg | Für Funk `MINDFLEX_EEG_TRANSPORT=ble` setzen und `MINDFLEX_EEG_PORT` weglassen |
| Headset per Funk nicht erreichbar | `ble_bridge.py` hält die Verbindung | dort mit Strg-C beenden |
| Genauigkeit 100 % | zu wenige getrennte Aufnahmen, Zufallssplit | je Befehl mindestens drei, besser fünf getrennte Aufnahmen |

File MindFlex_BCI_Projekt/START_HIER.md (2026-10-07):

# MindFlex BCI – so startest du das Programm

## Mac
1. Python 3 installieren (https://www.python.org/downloads/), falls noch nicht vorhanden.
2. Doppelklick auf `start.command`.
   - Beim ersten Start werden die nötigen Pakete automatisch installiert (Internet nötig, ein paar Minuten).
   - Meldet macOS „nicht verifizierter Entwickler": Rechtsklick auf `start.command` → Öffnen.

Alternativ im Terminal, in diesem Ordner:
```
pip3 install -r requirements.txt
python3 main.py
```

## Windows
`pip install -r requirements.txt` ausführen, dann Doppelklick auf `start.bat`.

## Wie es weitergeht
Bluetooth einrichten, erstes Profil anlegen, kalibrieren: siehe [`README.md`](README.md).

## Inhalt
- `main.py` und die übrigen `.py`-Dateien – das Programm
- `profile/` – entsteht beim ersten Start; Profile mit Trainingsdaten und Modellen
- `arduino/` – Sketches für EEG-Arduino (`mindflex_eeg`) und RC-Auto (`rc_car_4wd`, `rc_car_test`), mit der Arduino IDE hochladen

## Hardware
MindFlex-Headset mit Arduino Uno (USB oder BLE) und RC-Auto mit Arduino Duemilanove + BLE-Modul.
Ohne Hardware startet die Oberfläche, zeigt aber keine Daten.

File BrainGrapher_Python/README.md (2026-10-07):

# BrainGrapher (Python)

Nachbau des Processing-Sketches aus [`../BrainGrapher/`](../BrainGrapher) in Python mit
PyQt5 und pyqtgraph. Zeigt die rohen EEG-Werte des MindFlex-Headsets live an, ohne dass
Processing installiert sein muss.

```bash
pip install PyQt5 pyqtgraph pyserial
python main_pyqt.py
```

Original: [Processing Brain Grapher](https://github.com/kitschpatrol/Processing-Brain-Grapher)
von Eric Mika, MIT-Lizenz (siehe [`../BrainGrapher/LICENSE.txt`](../BrainGrapher/LICENSE.txt)).

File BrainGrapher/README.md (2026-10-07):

## Anbindung per Bluetooth (Ergänzung, 2026-09-23)

Dieser Sketch wurde so erweitert, dass er die EEG-Daten auch **kabellos**
empfangen kann — über das BLE-Modul am Arduino statt über USB.

**Warum es dafür ein zweites Programm braucht:** Processing kann kein
Bluetooth Low Energy. Seine `serial`-Bibliothek spricht serielle
Schnittstellen, und ein CC2541-Modul erzeugt unter macOS keine. Deshalb
läuft daneben `ble_bridge.py`: Es bedient die Funkstrecke und reicht jede
Zeile über eine lokale Netzwerkverbindung an Processing weiter.

```
MindFlex → Arduino → BLE-Modul ~~> ble_bridge.py → TCP → Brain Grapher
```

**Reihenfolge beim Start — erst die Brücke, dann der Sketch:**

1. Einmalig: `pip3 install bleak`
2. Im Terminal: `python3 ble_bridge.py`
   Warten, bis dort `Empfang laeuft` steht.
3. `BrainGrapher.pde` in Processing öffnen und starten.

Die Brücke verbindet sich nach einem Funkabriss von selbst neu und läuft,
bis du sie mit Strg-C beendest.

**Zurück auf Kabel:** In `BrainGrapher.pde` oben `USE_BLE = false;` setzen.
Dann gilt wieder der ursprüngliche Weg über den seriellen Anschluss, den
Index stellst du über `SERIAL_INDEX` ein. Die unveränderte Originaldatei
liegt als `BrainGrapher_original_seriell.pde.bak` daneben.

**Moduladresse:** Sie steht oben in `ble_bridge.py` und ist unter macOS
eine rechnerspezifische Kennung — auf einem anderen Mac muss sie neu
ermittelt werden (im BCI-Projektordner mit `python3 ble_scan.py`) und dann
über `MINDFLEX_EEG_BLE_ADDRESS` gesetzt werden.

---

##Processing Brain Grapher

####Overview
This is a simple Processing application for graphing changes in brain waves over time. It's designed to read data from a hacked MindFlex EEG headset connected via USB.

It's mostly a proof of concept, demonstrating how to parse serial packets from the Arduino Brain Library, monitor signal strength, etc.

`BrainGrapher.pde` is the main project file. Open this in the Processing PDE to work with the project.

You may need to modfiy the index value in the line `serial = new Serial(this, Serial.list()[0], 9600);` inside the app's `setup()` function file depending on which serial / USB port your Arduino is connected to. (Try ` Serial.list()[1]`, ` Serial.list()[2]`, ` Serial.list()[3]`, etc.)

####Repository Rename
This project was formerly “Processing-Brain-Grapher” on GitHub, but was renamed to just “BrainGrapher” in 2014 for simplicity's sake.

####Dependencies
- The core Processing project. Tested with [Processing 1.5.1](http://processing.org/download/) and [Processing 2.0a5](http://code.google.com/p/processing/downloads/list).

- Version 2.0.4 of the [ControlP5 GUI Library](http://www.sojamo.de/libraries/controlP5/) is included with this project in the `/code` folder. No installation is necessary.

- If you're using this with a hacked MindFlex, you'll need the [Arduino Brain Library](https://github.com/kitschpatrol/Brain) installed and running on your Arduino. Additional instructions at [frontiernerds.com/brain-hack](](http://frontiernerds.com/brain-hack). 

####Colophon
Created by Eric Mika at NYU ITP in the spring of 2010. Revised in Spring 2012 to keep up with Processing and ControlP5 updates. Updated once more in early 2014 with bundled dependencies and more fixes for Control P5.

####Contact
Eric Mika  
ermika@gmail.com  
@kitschpatrol

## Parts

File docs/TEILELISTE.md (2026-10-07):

# Teileliste

Alles, was man zum Nachbauen braucht. Verkabelung: [`images/wiring.svg`](images/wiring.svg),
Begründungen für die Bauteilwahl: [`ARCHITEKTUR.md`](ARCHITEKTUR.md#8-bauteilwahl-im-vergleich).

## EEG-Seite

| Anzahl | Bauteil | Hinweis |
|---|---|---|
| 1 | MindFlex-Headset (Mattel) | enthält das TGAM-Modul von NeuroSky; gebraucht oft günstig |
| 1 | Arduino Uno oder Nachbau | hier ein Funduino Uno |
| 1 | BLE-Modul CC2541 (HM-10, AT-09 o. ä.) | nur für den Funkbetrieb |
| 1 | 9-V-Block mit Batteriefach, Schalter und Hohlstecker 5,5 × 2,1 mm | Versorgung ohne USB-Kabel |
| – | dünne Litze, Lötkolben | zwei Drähte an T-Pin und GND des TGAM-Moduls |
| – | Klett- oder Kabelbinder | Arduino und Batteriefach am Headset befestigen |

## Auto-Seite

| Anzahl | Bauteil | Hinweis |
|---|---|---|
| 1 | Arduino Duemilanove oder Uno | hier ein Duemilanove (ATmega328P) |
| 1 | L293D-Motor-Shield (HW-130) | Adafruit Motor Shield v1 oder kompatibel |
| 4 | TT-Getriebemotor 3–6 V | gelbe Standard-Getriebemotoren |
| 4 | Rad für TT-Motoren | ca. 65 mm |
| 1 | BLE-Modul CC2541 (HM-10, AT-09 o. ä.) | |
| 1 | 9-V-Block mit Batterieclip | Stromversorgung des Autos |
| 8 | Schraube M3 mit Mutter | Motorhalter am Chassis (8 Bohrungen Ø 3 mm) |
| 1 | Chassis, 3D-gedruckt | [`hardware/chassis_car.stl`](../hardware/chassis_car.stl), z. B. aus PLA |
| – | Dupont-Kabel | Funkmodul und Motoren anschließen |

## Rechner und Software

| Was | Wofür |
|---|---|
| Rechner mit Bluetooth 4.0 oder neuer | Verbindung zum Auto; entwickelt und getestet auf macOS |
| [Python](https://www.python.org/downloads/) 3.12 | Hauptprogramm, Pakete in `MindFlex_BCI_Projekt/requirements.txt` |
| [Arduino IDE](https://www.arduino.cc/en/software) | Sketches hochladen |
| [Arduino Brain Library](https://github.com/kitschpatrol/Brain) | Sketch für den Uno |
| Adafruit Motor Shield Library **Version 1** (`AFMotor`) | Sketch für das Auto, über den Bibliotheksverwalter der Arduino IDE |
| [Processing](https://processing.org/download) mit ControlP5 | nur für den BrainGrapher |

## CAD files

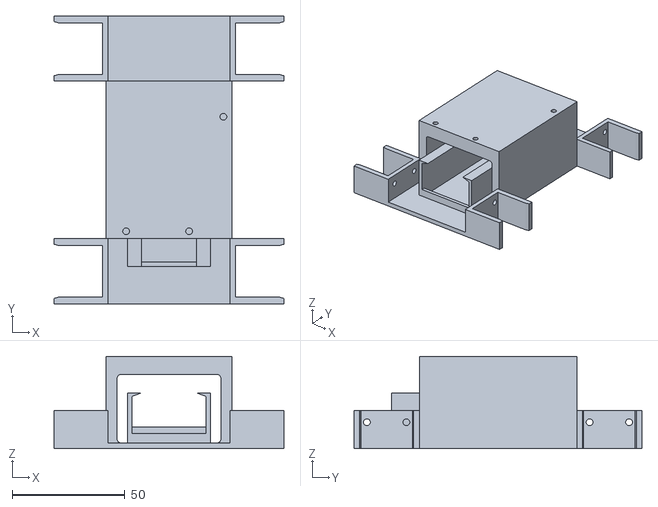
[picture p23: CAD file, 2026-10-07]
hardware/chassis_car.stl
102.0 x 127.7 x 41.0

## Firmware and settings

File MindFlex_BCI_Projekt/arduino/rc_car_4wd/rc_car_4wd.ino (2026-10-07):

/*
 * rc_car_4wd.ino
 * ===============
 *
 * Motorsteuerung des RC-Autos mit VIER Motoren ueber das
 * L293D-Motor-Shield (HW-130) und Bluetooth-Empfang.
 *
 * Panzer-Lenkung: Zum Drehen laeuft die eine Fahrzeugseite vorwaerts,
 * die andere rueckwaerts, das Auto dreht sich auf der Stelle.
 *
 * Befehle:
 *   'F' = alle vier Raeder vorwaerts
 *   'B' = alle vier Raeder rueckwaerts
 *   'L' = links rueckwaerts, rechts vorwaerts  -> dreht nach links
 *   'R' = links vorwaerts, rechts rueckwaerts  -> dreht nach rechts
 *   'S' = Stopp
 *
 * Zusaetzlich zum Einrichten (nur ueber den Seriellen Monitor gedacht):
 *   '1'..'4' = nur diesen einen Motor kurz vorwaerts laufen lassen
 *   'T'      = alle vier Motoren nacheinander testen
 *
 * ---------------------------------------------------------------------
 * DREHRICHTUNGEN EINSTELLEN
 * ---------------------------------------------------------------------
 * Motoren, die sich gegenueberliegen, sind spiegelverkehrt eingebaut --
 * dieselbe Polaritaet dreht sie also gegenlaeufig. Ausserdem kann jeder
 * Motor beim Anklemmen andersherum erwischt worden sein.
 *
 * Deshalb hat jeder Motor unten seinen eigenen Schalter in INVERT[].
 *
 * Stand 2026-09-17: Am realen Aufbau ausgemessen, zuletzt nach dem Tausch
 * der Anschluesse von M2 und M3. Alle vier Motoren liefen bei 'F'
 * gemeinsam rueckwaerts -- sie sind also einheitlich gepolt, nur eben
 * andersherum als der Sketch annimmt. Deshalb steht ueberall true. Beim
 * Umbau oder Neuanklemmen bitte erneut mit 'T' pruefen.
 *
 * Vorgehen:
 *
 *   1. Auto aufbocken, sodass die Raeder frei drehen
 *   2. Sketch hochladen, Seriellen Monitor oeffnen (9600 Baud)
 *   3. 'T' eingeben -- die vier Motoren laufen nacheinander je 1,5 s
 *   4. Notieren, welche Raeder sich dabei NICHT vorwaerts drehen
 *   5. Fuer genau diese Motoren unten den Wert auf true setzen
 *   6. Neu hochladen, 'T' wiederholen -- jetzt muessen alle vorwaerts drehen
 *
 * "Vorwaerts" heisst: Das Rad dreht sich so, dass das Auto nach vorne
 * fahren wuerde. Am besten von der Seite draufschauen.
 *
 * ---------------------------------------------------------------------
 * BENOETIGTE BIBLIOTHEK
 * ---------------------------------------------------------------------
 * "Adafruit Motor Shield library" Version 1 (AFMotor).
 *
 * ---------------------------------------------------------------------
 * MOTORANSCHLUESSE AM SHIELD
 * ---------------------------------------------------------------------
 *   M1 -> vorne rechts     M3 -> hinten rechts
 *   M2 -> vorne links      M4 -> hinten links
 *
 * (So ist es am realen Aufbau verkabelt, Stand 2026-08-15. Die Seiten
 * wechseln sich am Shield ab -- rechts haengt an M1 und M3, links an
 * M2 und M4.)
 *
 * ---------------------------------------------------------------------
 * BLUETOOTH-MODUL
 * ---------------------------------------------------------------------
 *   Modul VCC -> 3,3V         Modul TXD -> Pin 10
 *   Modul GND -> GND          Modul RXD -> Pin A0
 *
 * Alle Leitungen direkt verbunden, ohne Widerstaende.
 *
 * Der RXD-Pin wird nur fuer den Rueckkanal gebraucht: Ueber ihn meldet
 * der Arduino seinen Batteriestand zurueck an den Rechner.
 *
 * Ohne den Rueckkanal faehrt das Auto genauso -- dann bleibt RXD offen
 * und es kommt nur keine Batterieanzeige.
 *
 * ACHTUNG bei Pin 11: In vielen Anleitungen im Netz haengt der RXD-Pin des
 * Funkmoduls an Pin 11. Das geht hier NICHT, denn auf dem HW-130-Shield ist
 * Pin 11 der PWM-Ausgang von Motor 1. SoftwareSerial und die Motor-
 * bibliothek wuerden gleichzeitig auf denselben Pin schreiben.
 *
 * Pinbelegung des Shields zur Orientierung:
 *   3, 5, 6, 11  PWM fuer M2, M3, M4, M1
 *   4, 7, 8, 12  Schieberegister fuer alle Motoren
 *   9, 10        Servo-Anschluesse, frei solange kein Servo steckt
 *   2, 13, A0-A5 frei
 *
 * ---------------------------------------------------------------------
 * SICHERHEITSFUNKTION
 * ---------------------------------------------------------------------
 * Kommt laenger als COMMAND_TIMEOUT_MS kein Befehl an, stoppen die
 * Motoren. Die Python-Seite wiederholt den aktuellen Befehl alle 0,4
 * Sekunden, sodass das im Normalbetrieb nie zuschlaegt -- es greift nur,
 * wenn die Funkverbindung tatsaechlich abreisst.
 */

#include <AFMotor.h>
#include <SoftwareSerial.h>

// --- Bluetooth ---
const int PIN_BT_RX = 10;   // Arduino empfaengt hier <- Modul TXD
const int PIN_BT_TX = A0;   // Arduino sendet hier -> Modul RXD
                            // (NICHT Pin 11 -- das ist Motor 1)
const long BT_BAUD = 9600;

SoftwareSerial bluetooth(PIN_BT_RX, PIN_BT_TX);

// --- Motoren am Shield ---
AF_DCMotor motor1(1);   // vorne links
AF_DCMotor motor2(2);   // hinten links
AF_DCMotor motor3(3);   // vorne rechts
AF_DCMotor motor4(4);   // hinten rechts

AF_DCMotor* motors[4] = {&motor1, &motor2, &motor3, &motor4};

// Klartextnamen, nur fuer die Ausgabe im Seriellen Monitor.
const char* MOTOR_NAMES[4] = {
  "M1 vorne rechts", "M2 vorne links", "M3 hinten links", "M4 hinten rechts"
};

// Welche Seite ist welcher Motor? Wird nur fuers Drehen gebraucht -- auf
// Vorwaerts und Rueckwaerts hat es keinen Einfluss.
//
// Am realen Aufbau ausgemessen (2026-09-17, nach dem erneuten Umstecken).
// Rechts haengt an M1 und M4, links an M2 und M3. Die vorderen Raeder
// sitzen an M1/M2, die hinteren an M3/M4.
const bool IS_LEFT[4] = {false, true, true, false};

// ---------------------------------------------------------------------
// HIER die Drehrichtungen einstellen -- siehe Anleitung oben.
// true bedeutet: dieser Motor laeuft verkehrt herum und wird umgedreht.
// Startwert: die rechte Seite ist gespiegelt eingebaut, deshalb dort true.
// ---------------------------------------------------------------------
const bool INVERT[4] = {
  false,   // M1 vorne rechts   -- lief im Test rueckwaerts, deshalb gedreht
  true,    // M2 vorne links
  false,   // M3 hinten links   -- lief im Test rueckwaerts, deshalb gedreht
  true     // M4 hinten rechts
};

// --- Konfiguration ---
const int MOTOR_SPEED = 200;   // Geradeausfahrt, 0-255
const int TURN_SPEED  = 255;   // Drehen braucht mehr Kraft, weil die Raeder
                               // dabei seitlich ueber den Boden schleifen

const unsigned long COMMAND_TIMEOUT_MS = 1000;
const unsigned long TEST_RUN_MS = 1500;   // Laufzeit je Motor im Testmodus

const int PIN_LED = 13;        // leuchtet, solange ein Fahrbefehl aktiv ist

// --- Batterieanzeige (Rueckkanal zum Rechner) ---
//
// Ohne Zusatzteile misst der Chip seine eigene Betriebsspannung ueber die
// interne 1,1-V-Referenz. Das ist die geregelte 5-V-Schiene, nicht die
// Batterie -- der Wert faellt erst, wenn die Batterie so schwach wird,
// dass die Regelung zusammenbricht. Als Warnung taugt das, als
// Fuellstandsanzeige nicht.
//
// Mit Spannungsteiler an A1 wird die Batteriespannung direkt gemessen:
//
//   Vin --[ 100 kOhm ]--+-- A1
//                       |
//                   [ 47 kOhm ]
//                       |
//                      GND
const bool  SPANNUNGSTEILER_VORHANDEN = false;   // auf true, wenn verbaut
const int   PIN_BATTERIE = A1;
const float TEILER_FAKTOR = (100.0 + 47.0) / 47.0;
const int   DIODEN_OFFSET_MV = 400;              // Verpolungsschutz am Vin

const unsigned long BATTERIE_INTERVALL_MS = 5000;

unsigned long lastCommandTime = 0;
unsigned long letzteBatteriemeldung = 0;
char currentState = 'S';

void setup() {
  Serial.begin(9600);
  bluetooth.begin(BT_BAUD);

  pinMode(PIN_LED, OUTPUT);

  stopMotors();
  lastCommandTime = millis();

  Serial.println();
  Serial.println(F("RC-Auto 4WD bereit."));
  Serial.println(F("Fahren:  F=vor  B=zurueck  L=links  R=rechts  S=stopp"));
  Serial.println(F("Testen:  1-4 = einzelner Motor,  T = alle nacheinander"));
  Serial.println(F("--------------------------------------"));
}

void loop() {
  while (bluetooth.available() > 0) {
    handleByte(bluetooth.read(), "BT ");
  }

  while (Serial.available() > 0) {
    handleByte(Serial.read(), "USB");
  }

  if (currentState != 'S' && millis() - lastCommandTime > COMMAND_TIMEOUT_MS) {
    Serial.println(F("[!] Kein Befehl mehr empfangen -> STOPP"));
    stopMotors();
  }

  if (millis() - letzteBatteriemeldung >= BATTERIE_INTERVALL_MS) {
    letzteBatteriemeldung = millis();
    sendeBatteriestand();
  }
}

/**
 * Misst die Betriebsspannung des Chips ueber die interne 1,1-V-Referenz.
 *
 * @return Betriebsspannung in Millivolt.
 */
long messeVersorgung() {
  ADMUX = _BV(REFS0) | _BV(MUX3) | _BV(MUX2) | _BV(MUX1);
  delay(2);                                   // Referenz einschwingen lassen
  ADCSRA |= _BV(ADSC);
  while (bit_is_set(ADCSRA, ADSC)) {
    ;
  }
  long roh = ADCL | (ADCH << 8);
  if (roh == 0) {
    return 0;
  }
  return 1125300L / roh;
}

/**
 * Misst die Batteriespannung ueber den Spannungsteiler an A1.
 *
 * @return Batteriespannung in Millivolt.
 */
long messeBatterie() {
  long roh = analogRead(PIN_BATTERIE);
  long versorgung = messeVersorgung();
  long amPin = roh * versorgung / 1023;
  return (long) (amPin * TEILER_FAKTOR) + DIODEN_OFFSET_MV;
}

/**
 * Meldet den Batteriestand ueber Bluetooth an den Rechner.
 *
 * Format: BAT,<millivolt>,<modus>  --  modus 0 = Versorgung, 1 = Batterie.
 *
 * Waehrend SoftwareSerial sendet, sind die Interrupts kurz gesperrt, es
 * koennte also ein eingehendes Befehlszeichen verlorengehen. Das ist
 * unkritisch: Die Python-Seite wiederholt den aktuellen Fahrbefehl alle
 * 0,4 Sekunden, ein verlorenes Zeichen ist nach dem naechsten Takt
 * wieder ausgeglichen.
 */
void sendeBatteriestand() {
  long millivolt = SPANNUNGSTEILER_VORHANDEN ? messeBatterie() : messeVersorgung();

  bluetooth.print(F("BAT,"));
  bluetooth.print(millivolt);
  bluetooth.print(F(","));
  bluetooth.println(SPANNUNGSTEILER_VORHANDEN ? 1 : 0);

  // Zur Kontrolle auch ueber USB, falls der Monitor offen ist.
  Serial.print(F("[BAT] "));
  Serial.print(millivolt);
  Serial.println(F(" mV"));
}

/**
 * Verarbeitet ein empfangenes Byte.
 *
 * @param raw    Das empfangene Byte.
 * @param source Kurzname der Quelle, nur fuer die Ausgabe.
 */
void handleByte(int raw, const char* source) {
  char command = toupper((char) raw);

  // Testbefehle: einzelner Motor bzw. alle nacheinander
  if (command >= '1' && command <= '4') {
    testMotor(command - '1');
    return;
  }
  if (command == 'T') {
    testAll();
    return;
  }

  switch (command) {
    case 'F': driveForward();  break;
    case 'B': driveBackward(); break;
    case 'L': turnLeft();      break;
    case 'R': turnRight();     break;
    case 'S': stopMotors();    break;
    default:
      // Zeilenumbrueche und Stoerzeichen ignorieren, aber nicht stoppen.
      return;
  }

  lastCommandTime = millis();

  Serial.print(F("["));
  Serial.print(source);
  Serial.print(F("] "));
  Serial.println(command);
}

/**
 * Setzt einen einzelnen Motor.
 *
 * @param i         Index 0-3 (M1-M4).
 * @param vorwaerts True, wenn sich das Rad in Fahrtrichtung drehen soll.
 * @param speed     Geschwindigkeit 0-255.
 */
void setMotor(uint8_t i, bool vorwaerts, int speed) {
  // INVERT dreht die Bedeutung um, falls der Motor verkehrt angeklemmt ist.
  uint8_t richtung = (vorwaerts != INVERT[i]) ? FORWARD : BACKWARD;
  motors[i]->setSpeed(speed);
  motors[i]->run(richtung);
}

void driveForward() {
  currentState = 'F';
  for (uint8_t i = 0; i < 4; i++) setMotor(i, true, MOTOR_SPEED);
  digitalWrite(PIN_LED, HIGH);
}

void driveBackward() {
  currentState = 'B';
  for (uint8_t i = 0; i < 4; i++) setMotor(i, false, MOTOR_SPEED);
  digitalWrite(PIN_LED, HIGH);
}

void turnLeft() {
  // Linke Seite rueckwaerts, rechte vorwaerts -> Drehung nach links
  currentState = 'L';
  for (uint8_t i = 0; i < 4; i++) setMotor(i, !IS_LEFT[i], TURN_SPEED);
  digitalWrite(PIN_LED, HIGH);
}

void turnRight() {
  // Linke Seite vorwaerts, rechte rueckwaerts -> Drehung nach rechts
  currentState = 'R';
  for (uint8_t i = 0; i < 4; i++) setMotor(i, IS_LEFT[i], TURN_SPEED);
  digitalWrite(PIN_LED, HIGH);
}

void stopMotors() {
  currentState = 'S';
  for (uint8_t i = 0; i < 4; i++) motors[i]->run(RELEASE);
  digitalWrite(PIN_LED, LOW);
}

/**
 * Laesst einen einzelnen Motor kurz vorwaerts laufen.
 *
 * Zum Einrichten der Drehrichtungen: Man sieht sofort, welches Rad zu
 * welchem Anschluss gehoert und ob es richtig herum dreht.
 *
 * @param i Index 0-3 (M1-M4).
 */
void testMotor(uint8_t i) {
  if (i > 3) return;

  Serial.print(F("Test "));
  Serial.print(MOTOR_NAMES[i]);
  Serial.print(F("  (INVERT="));
  Serial.print(INVERT[i] ? F("true") : F("false"));
  Serial.println(F(") -> sollte VORWAERTS drehen"));

  stopMotors();
  setMotor(i, true, MOTOR_SPEED);
  delay(TEST_RUN_MS);
  stopMotors();

  lastCommandTime = millis();
}

/**
 * Testet alle vier Motoren nacheinander, mit Pause dazwischen.
 */
void testAll() {
  Serial.println(F("--- Motortest, alle vier nacheinander ---"));
  for (uint8_t i = 0; i < 4; i++) {
    testMotor(i);
    delay(700);
  }
  Serial.println(F("--- fertig. Welche Raeder liefen rueckwaerts? ---"));
  Serial.println(F("    Fuer die INVERT[] im Sketch umstellen."));
}

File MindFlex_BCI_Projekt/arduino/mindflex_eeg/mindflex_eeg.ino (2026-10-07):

/*
 * mindflex_eeg.ino
 * =================
 *
 * Liest das MindFlex-EEG-Headset aus und gibt die Messwerte als
 * CSV-Zeile weiter -- wahlweise ueber das USB-Kabel oder ueber ein
 * BLE-Funkmodul.
 *
 * Laeuft auf dem Arduino Uno. Gegenstueck auf dem Rechner ist
 * serial_receiver.py (Kabel) bzw. ble_serial_receiver.py (Funk).
 *
 * Beruht auf dem Beispiel BrainSerialTest der Arduino-Brain-Bibliothek
 * von Eric Mika. Gegenueber dem Original ist nur die Ausgabe
 * konfigurierbar gemacht worden, damit sie sich fuer die Funkstrecke
 * aufraeumen laesst.
 *
 * ---------------------------------------------------------------------
 * WIE DIE DATEN FLIESSEN
 * ---------------------------------------------------------------------
 * Der ThinkGear-Chip im Headset sendet dauerhaft. Sein T-Pin haengt am
 * RX-Pin (Pin 0) des Arduino. Die Bibliothek zerlegt diesen Bytestrom
 * und legt die Werte als fertige CSV-Zeile auf den TX-Pin (Pin 1).
 *
 * Beide Richtungen laufen also ueber dieselbe Hardware-Schnittstelle,
 * stoeren sich aber nicht: Pin 0 ist Eingang, Pin 1 ist Ausgang.
 *
 * Ausgabeformat, elf durch Kommas getrennte Werte:
 *
 *   SignalQuality, Attention, Meditation, Delta, Theta,
 *   LowAlpha, HighAlpha, LowBeta, HighBeta, LowGamma, HighGamma
 *
 * SignalQuality laeuft nach ThinkGear-Konvention andersherum als man
 * erwartet: 0 bedeutet perfekten Kontakt, 200 gar keinen. Die Python-
 * Seite rechnet das in Prozent um.
 *
 * ---------------------------------------------------------------------
 * VARIANTE 1 -- UEBER USB-KABEL
 * ---------------------------------------------------------------------
 *   MindFlex T-Pin -> Pin 0 (RX)
 *   MindFlex GND   -> GND
 *   Arduino        -> USB-Kabel zum Rechner
 *
 * Starten mit:
 *   MINDFLEX_EEG_PORT=/dev/cu.usbmodemXXXX python3 main.py
 *
 * ---------------------------------------------------------------------
 * VARIANTE 2 -- UEBER BLUETOOTH
 * ---------------------------------------------------------------------
 * Zusaetzlich zur Verkabelung oben kommt ein BLE-Modul der HM-10-Familie
 * (CC2541) an den Sendepin:
 *
 *   Modul VCC -> 3,3V
 *   Modul GND -> GND
 *   Modul RXD -> Pin 1 (TX)
 *   Modul TXD -> nicht anschliessen
 *
 * Alle Leitungen direkt verbunden, ohne Widerstaende.
 *
 * Am Sketch aendert sich dafuer nichts: Das Modul hoert einfach mit,
 * was ohnehin auf Pin 1 hinausgeht. Der Serielle Monitor am USB-Kabel
 * funktioniert parallel weiter, weil Pin 1 ein Ausgang ist und beide
 * Empfaenger dieselben Bytes bekommen.
 *
 * Adresse des Moduls ermitteln (mit ausgeschaltetem RC-Auto, sonst sind
 * die beiden Module nicht auseinanderzuhalten):
 *   python3 ble_scan.py
 *
 * Starten mit:
 *   MINDFLEX_EEG_TRANSPORT=ble MINDFLEX_EEG_BLE_ADDRESS=<UUID> python3 main.py
 *
 * ---------------------------------------------------------------------
 * BEIM HOCHLADEN
 * ---------------------------------------------------------------------
 * Der ThinkGear-Chip sendet in Pin 0 hinein und stoert dadurch den
 * Upload. Vor dem Hochladen das Headset ausschalten oder die Leitung
 * am RX-Pin abziehen.
 */

// ---------------------------------------------------------------------
// BATTERIEANZEIGE
// ---------------------------------------------------------------------
// Es gibt zwei Betriebsarten, umschaltbar ueber SPANNUNGSTEILER_VORHANDEN.
//
// OHNE ZUSATZTEILE (Standard):
//   Der ATmega328 misst seine eigene Betriebsspannung ueber die interne
//   1,1-V-Referenz. Gemessen wird damit die geregelte 5-V-Schiene, nicht
//   die Batterie. Solange der Regler genug Eingangsspannung hat, stehen
//   dort stur 5,00 V -- der Wert faellt erst, wenn die Batterie unter
//   etwa 7 V kommt und die Regelung zusammenbricht. Das ist also eine
//   Warnlampe, kein Tankanzeiger.
//
// MIT SPANNUNGSTEILER (genauer):
//   Zwei Widerstaende von Vin auf einen Analogeingang messen die
//   Batteriespannung direkt:
//
//     Vin --[ 100 kOhm ]--+-- A1
//                         |
//                     [ 47 kOhm ]
//                         |
//                        GND
//
//   Bei 9,6 V liegen dann 3,07 V am Eingang, also sicher unter 5 V.
//   Achtung: Ueber Vin liegt noch die Verpolungsschutz-Diode des Arduino
//   dazwischen, die Messung faellt rund 0,4 V zu niedrig aus. Wer es
//   genau will, greift direkt an der Batterie ab oder rechnet den Wert
//   in DIODEN_OFFSET_MV heraus.

#include <Brain.h>

// Die Bibliothek liest den Chip auf derselben Hardware-Schnittstelle,
// auf der sie auch ausgibt.
Brain brain(Serial);

// Muss zur Baudrate in config.py passen (CONFIG.eeg_serial.baudrate).
const long BAUD = 9600;

// Die Bibliothek kann zusaetzlich eine Fehlerzeile ausgeben. Am Kabel
// stoert die nicht, ueber Funk verdoppelt sie die uebertragene Menge --
// und die Python-Seite verwirft sie ohnehin, weil sie nicht elf Werte
// enthaelt. Zum Suchen von Kontaktproblemen kurz auf true stellen und
// den Seriellen Monitor mitlesen.
const bool FEHLER_MITSENDEN = false;

// --- Batterieanzeige ---
const bool SPANNUNGSTEILER_VORHANDEN = false;  // auf true, wenn verbaut
const int  PIN_BATTERIE = A1;
const float TEILER_FAKTOR = (100.0 + 47.0) / 47.0;   // 100k / 47k
const int  DIODEN_OFFSET_MV = 400;                   // Verpolungsschutz am Vin

// Abstand zwischen zwei Batteriemeldungen. Die Spannung aendert sich
// langsam, oefter als alle paar Sekunden braucht es nicht.
const unsigned long BATTERIE_INTERVALL_MS = 5000;

unsigned long letzteBatteriemeldung = 0;

void setup() {
    Serial.begin(BAUD);
}

void loop() {
    // Liefert etwa einmal pro Sekunde true, wenn ein vollstaendiges
    // Paket vom Headset angekommen ist.
    if (brain.update()) {
        if (FEHLER_MITSENDEN) {
            Serial.println(brain.readErrors());
        }
        Serial.println(brain.readCSV());
    }

    if (millis() - letzteBatteriemeldung >= BATTERIE_INTERVALL_MS) {
        letzteBatteriemeldung = millis();
        sendeBatteriestand();
    }
}

/**
 * Misst die Betriebsspannung des Chips ueber die interne 1,1-V-Referenz.
 *
 * Braucht keinerlei zusaetzliche Bauteile.
 *
 * @return Betriebsspannung in Millivolt.
 */
long messeVersorgung() {
    ADMUX = _BV(REFS0) | _BV(MUX3) | _BV(MUX2) | _BV(MUX1);
    delay(2);                                   // Referenz einschwingen lassen
    ADCSRA |= _BV(ADSC);
    while (bit_is_set(ADCSRA, ADSC)) {
        ;                                       // auf das Ergebnis warten
    }
    long roh = ADCL | (ADCH << 8);
    if (roh == 0) {
        return 0;
    }
    return 1125300L / roh;                      // 1,1 V * 1023 * 1000
}
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

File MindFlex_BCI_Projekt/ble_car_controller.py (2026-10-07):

"""
ble_car_controller.py
=====================

Steuert das RC-Auto ueber eine Bluetooth-Low-Energy-Funkstrecke.

Das Funkmodul am RC-Auto-Arduino ist ein CC2541 (HM-10-Familie). Es ist
*kein* HC-05: Es benutzt kein klassisches SPP-Profil, erscheint deshalb
nicht in den Bluetooth-Einstellungen und erzeugt keinen seriellen Port.
``pyserial`` kann es prinzipiell nicht ansprechen. Stattdessen wird ueber
GATT in die Charakteristik ``FFE1`` geschrieben; was dort ankommt, gibt
das Modul unveraendert an seinem TXD-Pin aus und landet damit beim
Arduino.

Gesendet werden dieselben Einzelzeichen wie bisher:

    F = FORWARD, B = BACKWARD, L = LEFT, R = RIGHT, S = STOP

Diese Klasse ist ein direkter Ersatz fuer ``car_controller.CarController``
und hat dieselbe Schnittstelle (``connect`` / ``send_label`` /
``disconnect`` sowie die Attribute ``connected`` und ``last_command``).

Technischer Hintergrund: ``bleak`` arbeitet asynchron, der Rest der
Anwendung (PyQt-GUI) synchron. Diese Klasse betreibt deshalb einen
eigenen Hintergrund-Thread mit eigener Event-Loop und reicht Aufrufe per
``run_coroutine_threadsafe`` hinein. Nach aussen bleibt alles synchron.

Sicherheitsprinzip wie beim seriellen Vorgaenger: Bei jedem Fehler
(Modul nicht gefunden, Verbindungsabbruch, Schreibfehler) wird eher kein
Befehl gesendet, als unkontrolliert weiterzufahren -- und der Rest der
Anwendung laeuft weiter, es werden dann nur keine Fahrbefehle gesendet.
"""

from __future__ import annotations

import asyncio
import threading
from typing import Any, Coroutine, TypeVar

from bleak import BleakClient, BleakScanner

from config import CONFIG, LABEL_TO_COMMAND, BleConfig
from utils import safe_execute, setup_logger

logger = setup_logger(__name__, CONFIG.paths.log_file)

T = TypeVar("T")


class BleCarController:
    """Sendet Fahrbefehle per Bluetooth Low Energy an den RC-Auto-Arduino.

    Attributes:
        ble_config: BLE-Konfiguration (Adresse, UUIDs, Zeitlimits).
        connected: ``True``, wenn aktuell eine offene Verbindung besteht.
        last_command: Zuletzt gesendetes Label, um doppeltes Senden
            desselben Befehls zu vermeiden.
    """

    def __init__(self, ble_config: BleConfig | None = None) -> None:
        """Initialisiert den Controller, baut aber noch keine Verbindung auf.

        Args:
            ble_config: BLE-Konfiguration. Default aus ``CONFIG.car_ble``.
        """
        self.ble_config = ble_config if ble_config is not None else CONFIG.car_ble
        self.connected = False
        self.last_command: str | None = None

        self._loop: asyncio.AbstractEventLoop | None = None
        self._thread: threading.Thread | None = None
        self._client: BleakClient | None = None
        self._char: Any = None
        self._write_response = True
        self._current_command: str | None = None
        self._heartbeat: asyncio.Task | None = None

        # Unterscheidet das planmaessige Trennen vom echten Verbindungsabriss,
        # damit nur letzterer als Warnung im Log landet.
        self._closing = False

    # ------------------------------------------------------------------
    # Oeffentliche Schnittstelle (synchron, wie beim seriellen Vorgaenger)
    # ------------------------------------------------------------------

    @safe_execute(logger, default=False)
    def connect(self) -> bool:
        """Startet den BLE-Thread und verbindet sich mit dem Funkmodul.

        Returns:
            ``True`` bei Erfolg, sonst ``False``. Ein fehlgeschlagener
            Verbindungsaufbau ist kein fataler Fehler -- Anzeige und
            Klassifikation laufen weiter, es werden dann nur keine
            Fahrbefehle gesendet.
        """
        self._closing = False
        self._start_loop()
        if self._loop is None:
            logger.error("BLE-Hintergrund-Thread konnte nicht gestartet werden.")
            return False

        # Grosszuegiges Zeitlimit: Suche plus Verbindungsaufbau.
        result = self._run(self._async_connect(), timeout=self.ble_config.scan_timeout + 20.0)
        self.connected = bool(result)
        return self.connected

    @safe_execute(logger, default=False)
    def send_label(self, label: str, force: bool = False) -> bool:
        """Uebersetzt ein Vorhersage-Label in ein Steuerzeichen und sendet es.

        Sendet nur, wenn sich der Befehl gegenueber dem zuletzt gesendeten
        unterscheidet (oder ``force=True``). Damit der Arduino trotzdem
        nicht in seinen Sicherheits-Timeout laeuft, wiederholt ein
        Hintergrund-Task den aktuellen Befehl regelmaessig (siehe
        ``BleConfig.resend_interval``).

        Args:
            label: Eines der Labels aus ``CONFIG.labels``.
            force: Wenn ``True``, wird auch bei unveraendertem Befehl
                erneut gesendet.

        Returns:
            ``True``, wenn ein Befehl tatsaechlich gesendet wurde.
        """
        command = LABEL_TO_COMMAND.get(label)
        if command is None:
            logger.warning("Unbekanntes Label fuer Fahrbefehl: %r", label)
            return False

        if not self.connected or self._loop is None:
            logger.debug("RC-Auto nicht verbunden, Befehl '%s' wird verworfen.", command)
            return False

        if not force and label == self.last_command:
            return False

        if not self._run(self._async_write(command), timeout=5.0):
            return False

        self.last_command = label
        self._current_command = command
        logger.debug("Fahrbefehl gesendet: %s (%s)", label, command)
        return True

    @safe_execute(logger)
    def disconnect(self) -> None:
        """Sendet vorsichtshalber STOP und faehrt die Verbindung herunter."""
        if self.connected:
            self.send_label("STOP", force=True)

        self._closing = True

        if self._loop is not None:
            self._run(self._async_disconnect(), timeout=10.0)
            self._loop.call_soon_threadsafe(self._loop.stop)

        if self._thread is not None:
            self._thread.join(timeout=5.0)

        self._loop = None
        self._thread = None
        self._client = None
        self._char = None
        self.connected = False

    # ------------------------------------------------------------------
    # Thread- und Loop-Verwaltung
    # ------------------------------------------------------------------

    def _start_loop(self) -> None:
        """Startet einmalig den Hintergrund-Thread mit eigener Event-Loop."""
        if self._loop is not None:
            return

        ready = threading.Event()

        def runner() -> None:
            loop = asyncio.new_event_loop()
            asyncio.set_event_loop(loop)
            self._loop = loop
            ready.set()
            loop.run_forever()
            loop.close()

        self._thread = threading.Thread(target=runner, name="ble-car", daemon=True)
        self._thread.start()
        ready.wait(timeout=5.0)
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

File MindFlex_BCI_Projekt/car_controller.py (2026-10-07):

"""
car_controller.py
==================

Steuert das RC-Auto ueber einen ZWEITEN Arduino, der die
Bewegungsbefehle in Motoransteuerung umsetzt (dieser Arduino-Code
existiert bereits und wird von diesem Projekt nicht veraendert).

Python sendet dazu ausschliesslich Einzelzeichen ueber die serielle
Schnittstelle:

    F = FORWARD, B = BACKWARD, L = LEFT, R = RIGHT, S = STOP

Sicherheitsprinzip: Bei jedem Fehler (Port nicht erreichbar, Schreib-
fehler, Verbindungsabbruch) faellt der Controller auf STOP zurueck bzw.
sendet erst gar keinen Bewegungsbefehl -- ein RC-Auto soll im
Zweifelsfall stehen bleiben, nicht unkontrolliert weiterfahren.
"""

from __future__ import annotations

import serial

from config import CONFIG, LABEL_TO_COMMAND, SerialConfig
from serial_receiver import resolve_port
from utils import safe_execute, setup_logger

logger = setup_logger(__name__, CONFIG.paths.log_file)


class CarController:
    """Sendet Fahrbefehle an den RC-Auto-Arduino.

    Attributes:
        serial_config: Serielle Konfiguration fuer die Auto-Verbindung.
        connected: ``True``, wenn aktuell eine offene Verbindung besteht.
        last_command: Zuletzt tatsaechlich gesendeter Befehl (Label),
            um doppeltes Senden desselben Befehls zu vermeiden.
    """

    def __init__(self, serial_config: SerialConfig | None = None) -> None:
        """Initialisiert den Controller, oeffnet aber noch keine Verbindung.

        Args:
            serial_config: Serielle Konfiguration. Default aus
                ``CONFIG.car_serial``.
        """
        self.serial_config = serial_config if serial_config is not None else CONFIG.car_serial
        self.connected = False
        self.last_command: str | None = None
        self._serial: serial.Serial | None = None

    @safe_execute(logger, default=False)
    def connect(self) -> bool:
        """Oeffnet die serielle Verbindung zum RC-Auto-Arduino.

        Returns:
            ``True`` bei Erfolg, sonst ``False``. Ein fehlgeschlagener
            Verbindungsaufbau ist kein fataler Fehler -- der Rest des
            Programms (Anzeige/Klassifikation) laeuft trotzdem weiter,
            es werden dann nur keine Fahrbefehle gesendet.
        """
        port_name = resolve_port(self.serial_config)
        if not port_name:
            logger.warning(
                "Kein serieller Port fuer das RC-Auto gefunden (hint=%r).",
                self.serial_config.port_hint,
            )
            self.connected = False
            return False

        try:
            self._serial = serial.Serial(
                port_name, self.serial_config.baudrate, timeout=self.serial_config.timeout
            )
            self.connected = True
            logger.info("RC-Auto verbunden ueber %s.", port_name)
            return True
        except serial.SerialException as exc:
            logger.error("Konnte RC-Auto-Port %s nicht oeffnen: %s", port_name, exc)
            self.connected = False
            return False

    @safe_execute(logger)
    def disconnect(self) -> None:
        """Sendet vorsichtshalber STOP und schliesst die Verbindung."""
        if self.connected:
            self.send_label("STOP", force=True)
        if self._serial is not None and self._serial.is_open:
            self._serial.close()
        self.connected = False

    @safe_execute(logger, default=False)
    def send_label(self, label: str, force: bool = False) -> bool:
        """Uebersetzt ein Vorhersage-Label in ein Steuerzeichen und sendet es.

        Sendet nur, wenn sich der Befehl gegenueber dem zuletzt
        gesendeten unterscheidet (oder ``force=True``), um die serielle
        Leitung nicht unnoetig mit identischen Befehlen zu fluten.

        Args:
            label: Eines der Labels aus ``CONFIG.labels``.
            force: Wenn ``True``, wird auch bei unveraendertem Befehl
                erneut gesendet.

        Returns:
            ``True``, wenn ein Befehl tatsaechlich gesendet wurde.
        """
        command = LABEL_TO_COMMAND.get(label)
        if command is None:
            logger.warning("Unbekanntes Label fuer Fahrbefehl: %r", label)
            return False

        if not self.connected or self._serial is None:
            logger.debug("RC-Auto nicht verbunden, Befehl '%s' wird verworfen.", command)
            return False

        if not force and label == self.last_command:
            return False

        try:
            self._serial.write(command.encode("ascii"))
        except serial.SerialException as exc:
            logger.error("Fehler beim Senden an das RC-Auto: %s", exc)
            self.connected = False
            return False

        self.last_command = label
        logger.debug("Fahrbefehl gesendet: %s (%s)", label, command)
        return True

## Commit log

2026-10-07 MindFlex BCI-Auto: Code, Architektur und 3D-Modell
    [Chassis BCI Seminar Car CAD-Print_v25_Schwelle5-Nase20.stl]
2026-10-07 Repo neu strukturiert: README mit Screenshots, Ablaufdiagramm, Lizenzen
    [chassis_v25.stl]
2026-10-07 Fotos von Headset und Auto, weitere Screenshots
2026-10-07 Chassis-STL in chassis_car.stl umbenannt
    [chassis_car.stl]
2026-10-07 Chassis-Bilder in chassis-car umbenannt
2026-10-07 Doku auf v3.4: Architektur neu, Teileliste, Schaltplan, Ergebnisse, englische README
    - docs/ARCHITEKTUR.md anhand des Codes neu geschrieben, falsche Angaben korrigiert
    - docs/TEILELISTE.md und docs/images/wiring.svg neu
    - README.md auf Englisch, deutsche Fassung in README.de.md
    - Ergebnisse mit Genauigkeit, Basisrate und Entwicklung
    - Bildunterschriften des Headsets präzisiert
    - Anleitung im Programmordner für Mac und Windows, Profile
    - ungenutztes trained_model.pkl entfernt (Modelle liegen je Profil)
2026-10-07 Schaltplan und Doku: Funkmodule ohne Widerstände angeschlossen, wie im echten Aufbau
2026-10-07 Auto läuft mit 9-V-Block; Widerstände aus allen Schaltplänen entfernt; Fotobeschriftungen korrigiert
    - Stromversorgung des Autos: 9-V-Block statt 4 × AA (Schaltplan, Teileliste, Architektur)
    - Spannungsteiler aus den Schaltplan-Kommentaren der Sketches und von ble_serial_receiver.py entfernt
    - Auto-Fotos nach sichtbarer Seite statt vorn/hinten beschriftet, englische README zweisprachig
    [ble_serial_receiver.py, mindflex_eeg.ino, rc_car_4wd.ino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]
2026-10-07 Funkmodule an 3,3 V statt 5 V (Schaltplan, Doku, Kommentare)
2026-10-07 Vorderansicht des Headsets oben über dem Auto-Foto
2026-10-07 Entwicklungsverlauf aus README und Architektur entfernt
